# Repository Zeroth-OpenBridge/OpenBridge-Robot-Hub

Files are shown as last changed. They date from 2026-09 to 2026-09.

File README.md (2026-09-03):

# Robot Hub

Hardware boundary for **Zeroth Bridge** (小桥): drawings, electrical topology, enclosure / interface notes, and printable parts.

OpenBridge is the open-source ecosystem. Zeroth Bridge is the robot.

| Resource | Repository |
| --- | --- |
| Product introduction | [openbridge](https://github.com/Zeroth-OpenBridge/openbridge) |
| Skill development | [Skill Hub](https://github.com/Zeroth-OpenBridge/OpenBridge-Skill-Hub) |
| Simulation and verification | [Simulation Hub](https://github.com/Zeroth-OpenBridge/OpenBridge-Simulation-Hub) |

Document version: V1.1.1  
Hardware snapshot: **2026-09-02** (`mechanical/20260902/`)  
Applicable model: 小桥 / Zeroth Bridge  
Units: SI (cm, kg, N·m)  
License: [GNU General Public License v3.0](LICENSE) — 元点机器人 / OpenBridge

---

## Contents

1. [Repository layout](#repository-layout)
2. [Print quickstart](#print-quickstart)
3. [Parts snapshot 2026-09-02](#parts-snapshot-2026-09-02)
4. [Mechanical structure](#mechanical-structure)
5. [Specifications](#specifications)
6. [Degrees of freedom](#degrees-of-freedom)
7. [Electrical topology](#electrical-topology)
8. [Assembly](#assembly)
9. [Known limits](#known-limits)
10. [Issues and pull requests](#issues-and-pull-requests)
11. [License](#license)

---

## Repository layout

```
OpenBridge-Robot-Hub/
├── README.md
├── CHANGELOG.md
├── LICENSE
├── images/                      README figures (regular Git files, not LFS)
│   ├── 2.2-electrical-topology.png
│   ├── 4.1-structure.png        body structure diagram
│   └── 4.1-joints.png           joint index / motor layout
├── mechanical/
│   └── 20260902/                hardware snapshot 2026-09-02
│       ├── VERSION
│       ├── Zeroth_Bridge_assembly_20260902.step.zip
│       ├── head/
│       ├── torso/
│       ├── waist/
│       ├── left_arm/
│       ├── right_arm/
│       ├── left_leg/
│       ├── right_leg/
│       └── foot/
├── electrical/                  topology and wiring
│   └── electrical-topology.pdf  source diagram from the open-source prep doc
└── assembly/                    assembly and fastener notes
```

| Path | Status | What belongs here |
| --- | --- | --- |
| `mechanical/20260902/` | Published | Printable STL by body region, structural members, and zipped STEP assembly (snapshot 2026-09-02) |
| `electrical/` | Topology PDF published | Electrical topology and later wiring / pinout notes |
| `assembly/` | Placeholder | Assembly sequence and fasteners |
| `images/` | Published | Figures used by this README |

Later hardware drops use a new dated folder (`mechanical/YYYYMMDD/`) so snapshots stay side by side.

---

## Print quickstart

Current parts: [`mechanical/20260902/`](mechanical/20260902/). Left / right parts use `_L` / `_R`. Files named `structure_*` are structural members (series **1** foot, **2** shank, **3** thigh, **4–5** waist, **6** arm).

Print **TPU** for:

- Chest enclosure — `torso/body_front_shell.stl`, `torso/body_rear_shell.stl` (soft chest shell)
- `head/neck_tpu.stl`
- `torso/logo_tpu.stl`
- `foot/foot_sole_tpu.stl`

Slicer profiles and remaining material assignments are not in this revision.

Coming soon. Expected update in September.

---

## Parts snapshot 2026-09-02

Full-body STEP (zipped, about 28 MB): [`Zeroth_Bridge_assembly_20260902.step.zip`](mechanical/20260902/Zeroth_Bridge_assembly_20260902.step.zip). Uncompressed STEP (134 MB): [Releases](https://github.com/Zeroth-OpenBridge/OpenBridge-Robot-Hub/releases/tag/hardware-2026.09.02).

| Region | Path | Files |
| --- | ---: | --- |
| Head | [`head/`](mechanical/20260902/head/) | 9 STL |
| Torso | [`torso/`](mechanical/20260902/torso/) | 18 STL |
| Waist | [`waist/`](mechanical/20260902/waist/) | 11 STL |
| Left arm | [`left_arm/`](mechanical/20260902/left_arm/) | 17 STL |
| Right arm | [`right_arm/`](mechanical/20260902/right_arm/) | 18 STL |
| Left leg | [`left_leg/`](mechanical/20260902/left_leg/) | 24 STL + 1 PRT |
| Right leg | [`right_leg/`](mechanical/20260902/right_leg/) | 21 STL |
| Foot | [`foot/`](mechanical/20260902/foot/) | 9 STL |
| Assembly | [`Zeroth_Bridge_assembly_20260902.step.zip`](mechanical/20260902/Zeroth_Bridge_assembly_20260902.step.zip) | 1 ZIP |

Filenames match the part names (English). `_L` / `_R` is side. Browse each folder for the full list.

---

## Mechanical structure

Zeroth Bridge is a compact humanoid with a slender body. Key dimensions and mass follow the [specification table](#specifications) (85 cm / about 10 kg). The chest shell is soft TPU.

**Body structure diagram**

<p align="center">
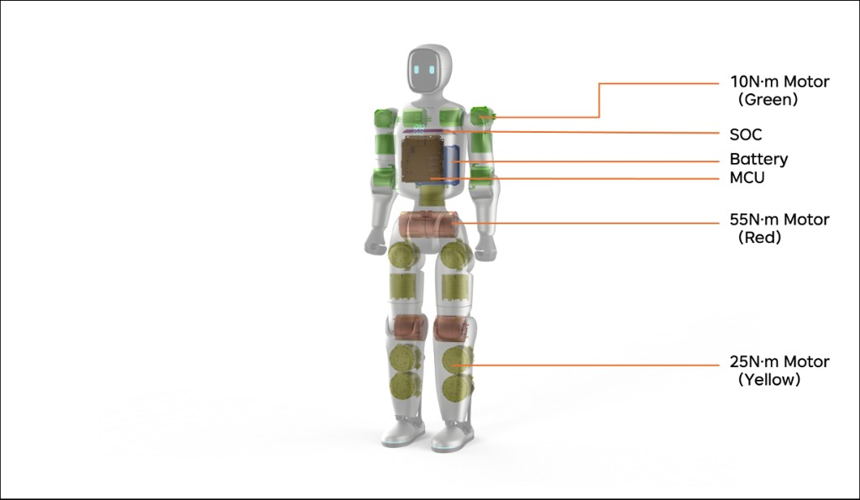
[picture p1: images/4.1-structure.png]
Zeroth Bridge body structure
  
</p>

Callouts on the cutaway:

- **10 N·m motor** (green) — shoulders and arms
- **SOC** — upper chest, below the neck
- **Battery** — blue pack in the torso
- **MCU** — chest controller board
- **55 N·m motor** (red) — hips and knees
- **25 N·m motor** (yellow) — thighs and ankles

**Joint range of motion and motor parameters**

<p align="center">
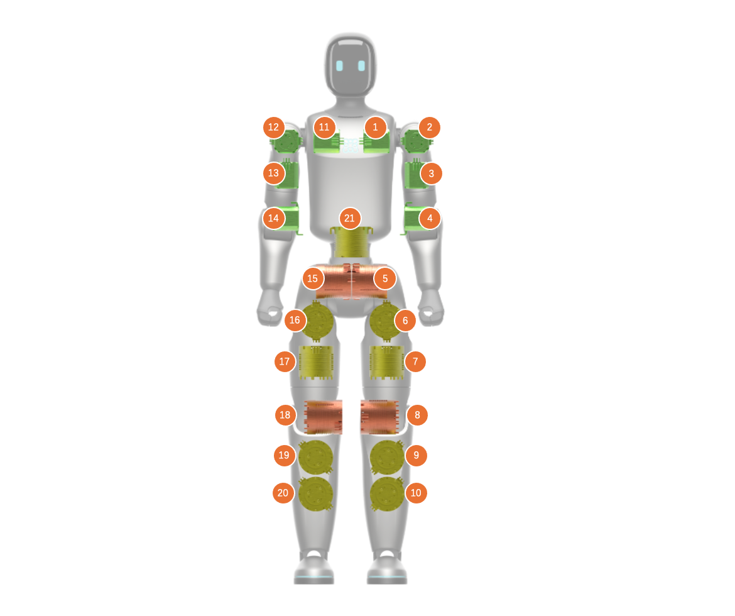
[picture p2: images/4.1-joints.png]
Joint range of motion and motor parameters
  
</p>

Orange tags **1–21** index joints: **1–4 right arm, 5–10 right leg, 11–14 left arm, 15–20 left leg, 21 waist.** Peak torques for each region are in the [DoF table](#degrees-of-freedom).

| # | Joint | Lower (deg) | Lower (rad) | Upper (deg) | Upper (rad) | Torque (N·m) | Speed (rpm) | Speed (rad/s) |
| --- | --- | ---: | ---: | ---: | ---: | ---: | ---: | ---: |
| 1 | right_shoulder_pitch | -210 | -3.6652 | 90 | 1.5708 | 10 | 235 | 24.6091 |
| 2 | right_shoulder_roll | -180 | -3.1416 | 10 | 0.1745 | 10 | 235 | 24.6091 |
| 3 | right_shoulder_yaw | -90 | -1.5708 | 90 | 1.5708 | 10 | 235 | 24.6091 |
| 4 | right_elbow_pitch | -45 | -0.7854 | 225 | 3.927 | 10 | 235 | 24.6091 |
| 5 | right_hip_pitch | -160 | -2.7925 | 160 | 2.7925 | 55 | 180 | 18.8496 |
| 6 | right_hip_roll | -80 | -1.3963 | 90 | 1.5708 | 25 | 170 | 17.8024 |
| 7 | right_hip_yaw | -160 | -2.7925 | 160 | 2.7925 | 25 | 170 | 17.8024 |
| 8 | right_knee_pitch | -100 | -1.7453 | 120 | 2.0944 | 55 | 180 | 18.8496 |
| 9 | right_ankle_pitch | -40 | -0.6981 | 40 | 0.6981 | 25 | 170 | 17.8024 |
| 10 | right_ankle_roll | -28 | -0.4887 | 28 | 0.4887 | 25 | 170 | 17.8024 |
| 11 | left_shoulder_pitch | -210 | -3.6652 | 90 | 1.5708 | 10 | 235 | 24.6091 |
| 12 | left_shoulder_roll | -10 | -0.1745 | 180 | 3.1416 | 10 | 235 | 24.6091 |
| 13 | left_shoulder_yaw | -90 | -1.5708 | 90 | 1.5708 | 10 | 235 | 24.6091 |
| 14 | left_elbow_pitch | -45 | -0.7854 | 225 | 3.927 | 10 | 235 | 24.6091 |
| 15 | left_hip_pitch | -160 | -2.7925 | 160 | 2.7925 | 55 | 180 | 18.8496 |
| 16 | left_hip_roll | -90 | -1.5708 | 80 | 1.3963 | 25 | 170 | 17.8024 |
| 17 | left_hip_yaw | -160 | -2.7925 | 160 | 2.7925 | 25 | 170 | 17.8024 |
| 18 | left_knee_pitch | -100 | -1.7453 | 120 | 2.0944 | 55 | 180 | 18.8496 |
| 19 | left_ankle_pitch | -40 | -0.6981 | 40 | 0.6981 | 25 | 170 | 17.8024 |
| 20 | left_ankle_roll | -28 | -0.4887 | 28 | 0.4887 | 25 | 170 | 17.8024 |
| 21 | waist_yaw | -155 | -2.7053 | 155 | 2.7053 | 25 | 170 | 17.8024 |

---

## Specifications

| Key spec | Value | Notes |
| --- | --- | --- |
| Overall height | 85 cm | ~80 cm-class small humanoid; suited to demonstrations, education, teleoperation, and small-object interaction |
| Shoulder height | 73 cm | Suited to low tabletops, children's desks, and near-floor motion demos; not suited to fine manipulation at adult kitchen counters |
| Hip / base height | 50 cm | Sets gait center of mass, fall height, and safety-test bounds |
| Leg length | ~50 cm | Structural segment length affects routing, enclosure, and mechanical stacking; Z-axis projected length affects standing height and gait |
| Arm length | 30–40 cm, two-finger gripper | Short-arm motion demo / teleoperation platform |
| Shoulder width | 13 cm between joint centers | Controlled without sacrificing self-collision clearance |
| Overall mass | ~10 kg | Lightweight, highly dynamic |

---

## Degrees of freedom

| Body region | Joint | DoF | Peak torque |
| --- | --- | --- | --- |
| Arms | Shoulder up/down | 1 | 10 N·m |
|  | Shoulder front/back | 1 | 10 N·m |
|  | Shoulder in/out | 1 | 10 N·m |
|  | Elbow up/down | 1 | 10 N·m |
| Waist | Waist rotation | 1 | 25 N·m |
| Legs | Hip | 1 | 55 N·m |
|  | Thigh | 2 | 25 N·m |
|  | Knee | 1 | 55 N·m |
|  | Ankle | 2 | 25 N·m |

---

## Electrical topology

Original file: [`electrical/electrical-topology.pdf`](electrical/electrical-topology.pdf). 

<p align="center">
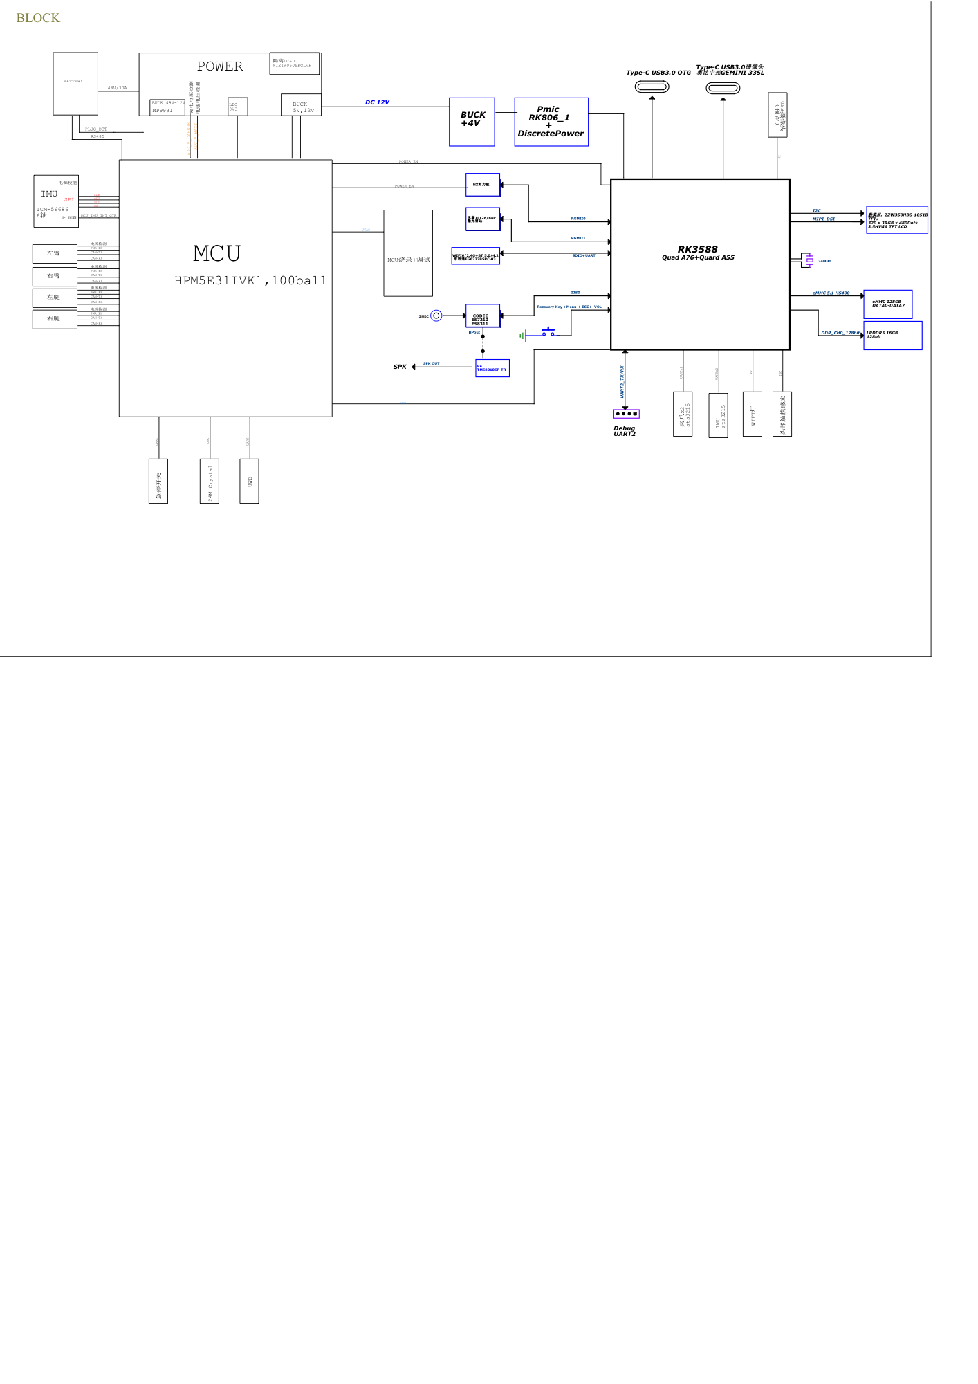
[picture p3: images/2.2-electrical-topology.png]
Zeroth Bridge electrical topology
  
</p>

Two compute domains share the body:

- **MCU** (HPM5E31IVK1) — real-time motion. Dedicated buses to left arm, right arm, left leg, and right leg; IMU on SPI/I2C; crystal, USB, and a programming/debug path toward the SoC.
- **SoC** (RK3588, quad-core A76 + quad-core A55) — application compute. LPDDR5 16 GB, eMMC 128 GB (HS400), LCD (320×384 @ 60 Hz), audio codec ES7210 / ES8311 to speaker, Wi-Fi/BT, USB 3.0 Type-C OTG, Type-C for GEMINI 335L, debug UART2, fan control, and a 9-axis gyro link.

MCU and SoC exchange data over dual **RGMII** links. Battery power goes through a **12 V buck**; the MCU rail set is 12 V / 5 V / 3.3 V; the SoC path is 12 V → buck +4 V → PMIC RK806 plus discrete regulators.

---

## Assembly

Coming soon. Expected update in September.

---

## Known limits

- Current sensing is IMU plus motor-internal feedback. LiDAR and cameras are not fitted; hardware interfaces are reserved.
- Collision energy is lower than a hard enclosure, but this is still a high-dynamic ~10 kg machine.
- Arm reach is short (30–40 cm). Not intended for fine work at adult kitchen-counter height.
- Fasteners and assembly steps are not published in this revision. Printable STL and the STEP assembly are in `mechanical/20260902/`.

If you build or modify a complete robot yourself, assess close-to-people use and high-dynamic motion risk on your own.

---

## Issues and pull requests

Use [GitHub Issues](https://github.com/Zeroth-OpenBridge/OpenBridge-Robot-Hub/issues) for defects, missing files, and doc gaps. Pull requests should stay scoped (one drawing set, one electrical note, or one README fix). Do not commit secrets or files over 100 MB; attach those to Releases.

Each public release is recorded in [CHANGELOG.md](CHANGELOG.md) and tagged.

---

## License

[GNU General Public License v3.0](LICENSE). Copyright 2026 元点机器人 / OpenBridge.

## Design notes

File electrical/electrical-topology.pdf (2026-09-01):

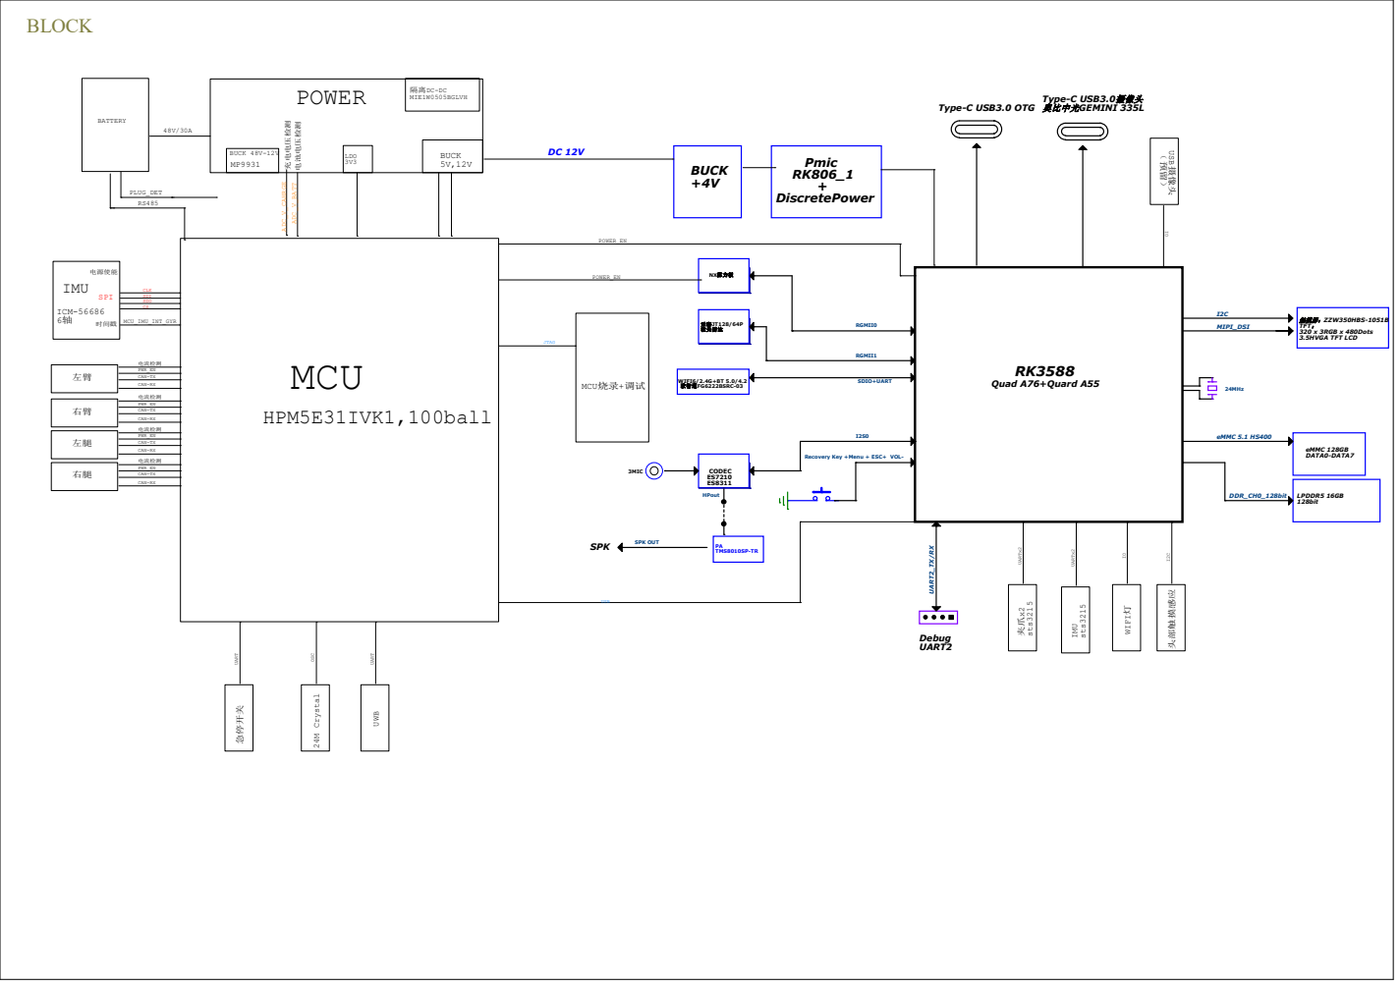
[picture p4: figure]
BLOCK; MCU; HPM5E31IVK1,100ball; IMU; ICM-56686 6轴; CLK; MCU_IMU_INT_GYR 左臂; SDI SDO CS; CAN-TX; BUCK 48V-12V ADC_V_CAHRGE; ADC_V_BATT 充电电压检测 电池电压检测; POWER; BUCK 5V,12V; LDO 3V3; POWER_EN; JTAG; MCU烧录+调试; 电源使能; SPI 时间戳; BATTERY; PLUG_DET; CAN-RX; PWR_EN 右臂; PWR_EN; CAN-RX 左腿; CAN-RX 右腿; 电流检测; WIFI6/2.4G+BT 5.0/4.2 欧智通FG6222BSRC-03; 禾赛JT128/64P 激光雷达; NX算力板; SDIO+UART; DDR_CH0_128bit; RGMII0; RGMII1; Type-C USB3.0摄像头 奥比中光GEMINI 335L; SPK; Recovery Key +Menu + ESC+ VOL-; Debug UART2; eMMC 128GB DATA0-DATA7; 24MHz; eMMC 5.1 HS400; Quad A76+Quard A55; PA TMS8010SP-TR; HPout; CODEC ES7210 ES8311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

I2C UARTx2 夹爪x2 sts3215 | UARTx2 IMU sts3215 急停开关 UART | WIFI灯 IO | IO USB摄像头 （预留） I2C 头部触摸感应 24M Crystal OSC

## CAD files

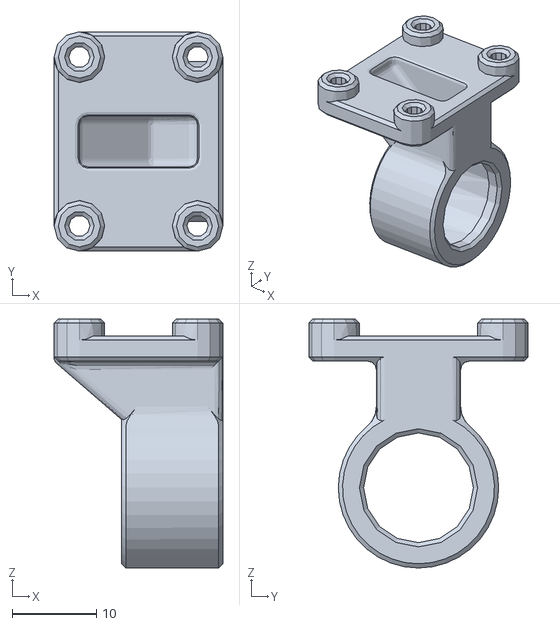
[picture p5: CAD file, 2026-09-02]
mechanical/20260902/foot/structure_1_1-01.stl
20.0 x 26.0 x 29.5

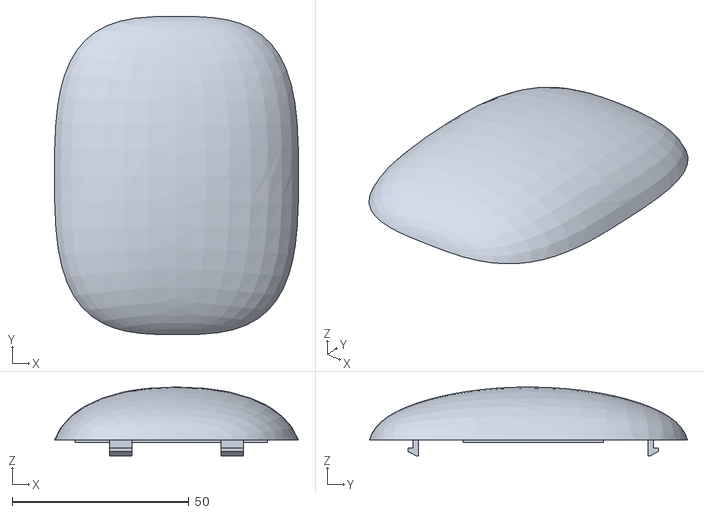
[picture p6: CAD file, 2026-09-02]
mechanical/20260902/head/face_shell.stl
69.0 x 90.0 x 19.5

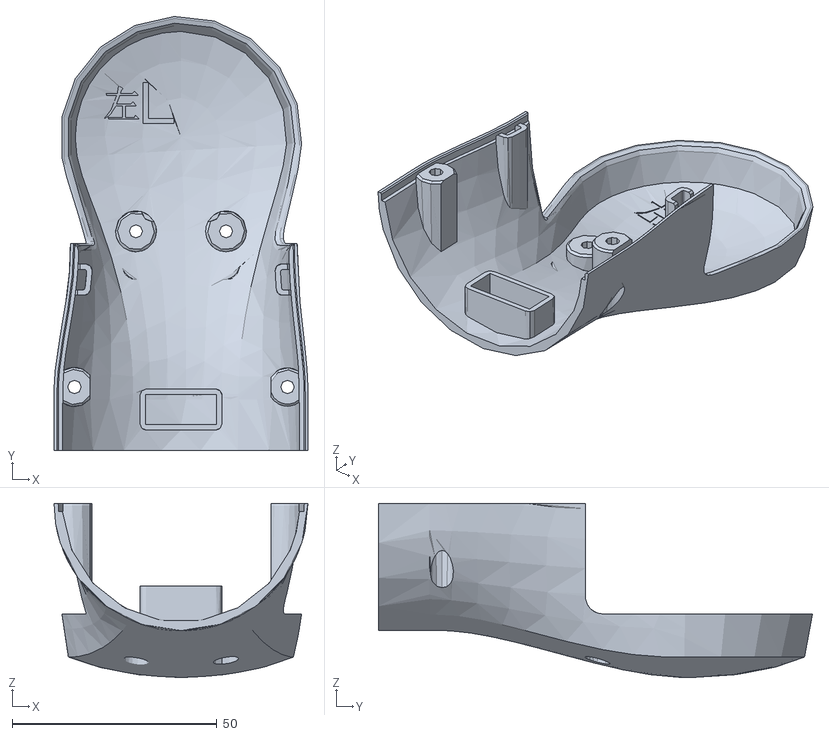
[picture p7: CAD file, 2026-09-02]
mechanical/20260902/left_arm/upper_arm_back_cover_L.stl
62.0 x 105.9 x 42.5

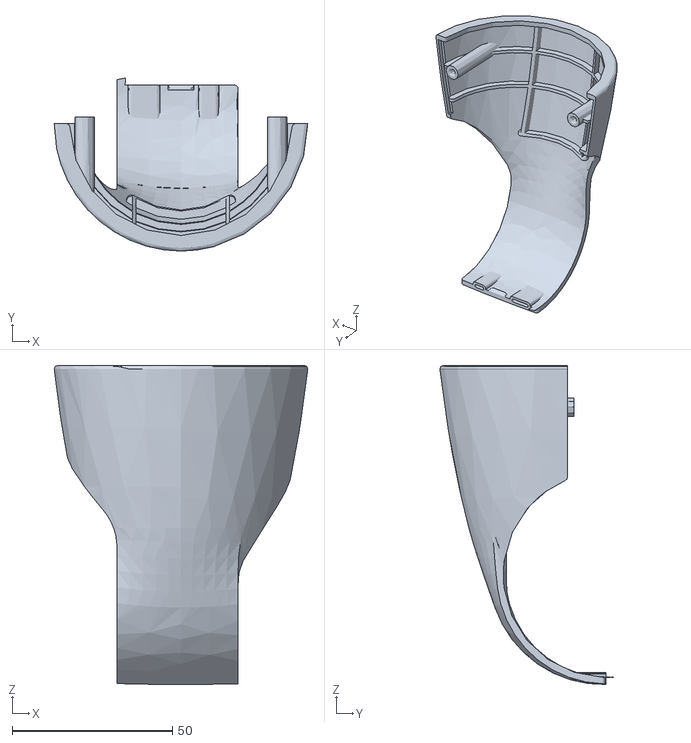
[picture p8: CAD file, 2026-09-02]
mechanical/20260902/left_leg/knee_front_shell_L.stl
79.1 x 54.0 x 99.5

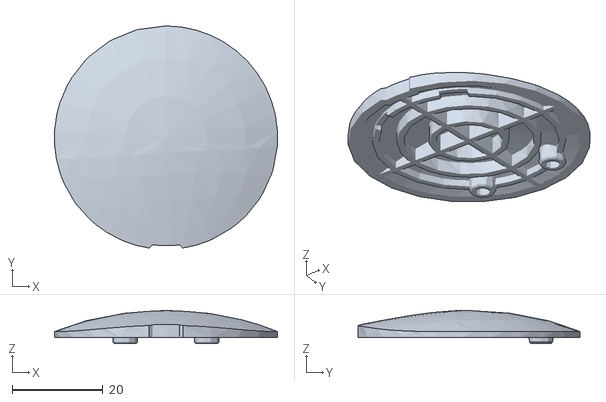
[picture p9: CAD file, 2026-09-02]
mechanical/20260902/right_arm/shoulder_servo_cover.stl
49.1 x 48.9 x 7.30

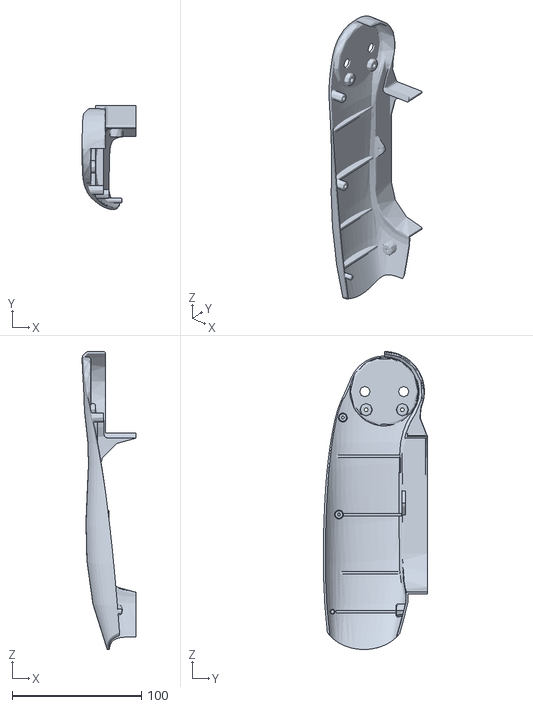
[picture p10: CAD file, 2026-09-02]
mechanical/20260902/right_leg/shank_outer_shell_R.stl
41.5 x 80.6 x 230.2

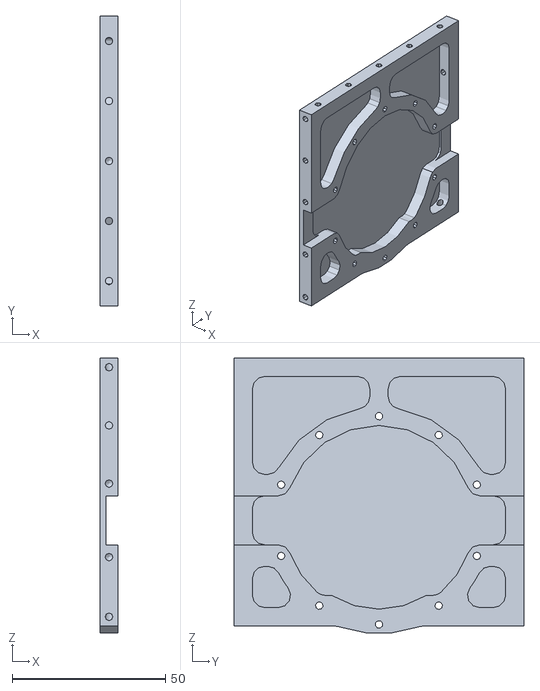
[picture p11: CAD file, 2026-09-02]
mechanical/20260902/torso/frame_battery_bottom.stl
6.00 x 94.7 x 89.8

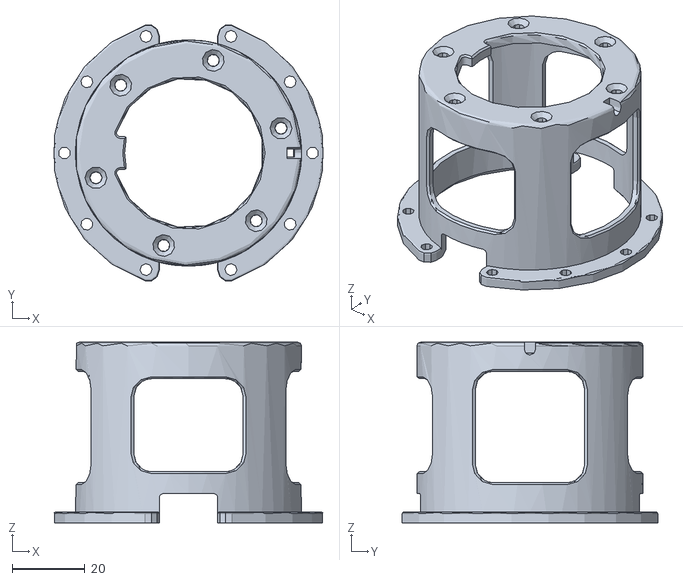
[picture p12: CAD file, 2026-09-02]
mechanical/20260902/waist/structure_5-1.stl
73.7 x 70.1 x 49.5

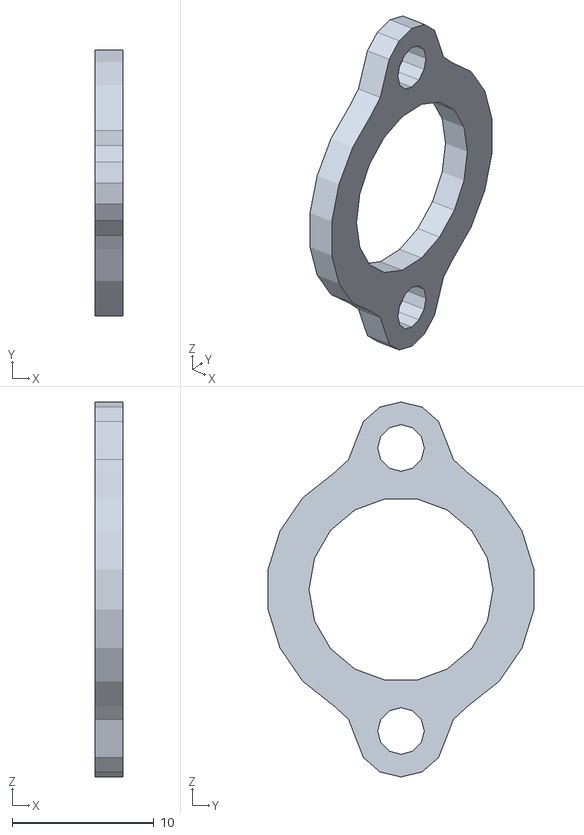
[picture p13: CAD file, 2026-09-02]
mechanical/20260902/foot/structure_1-3.stl
2.00 x 18.8 x 26.5

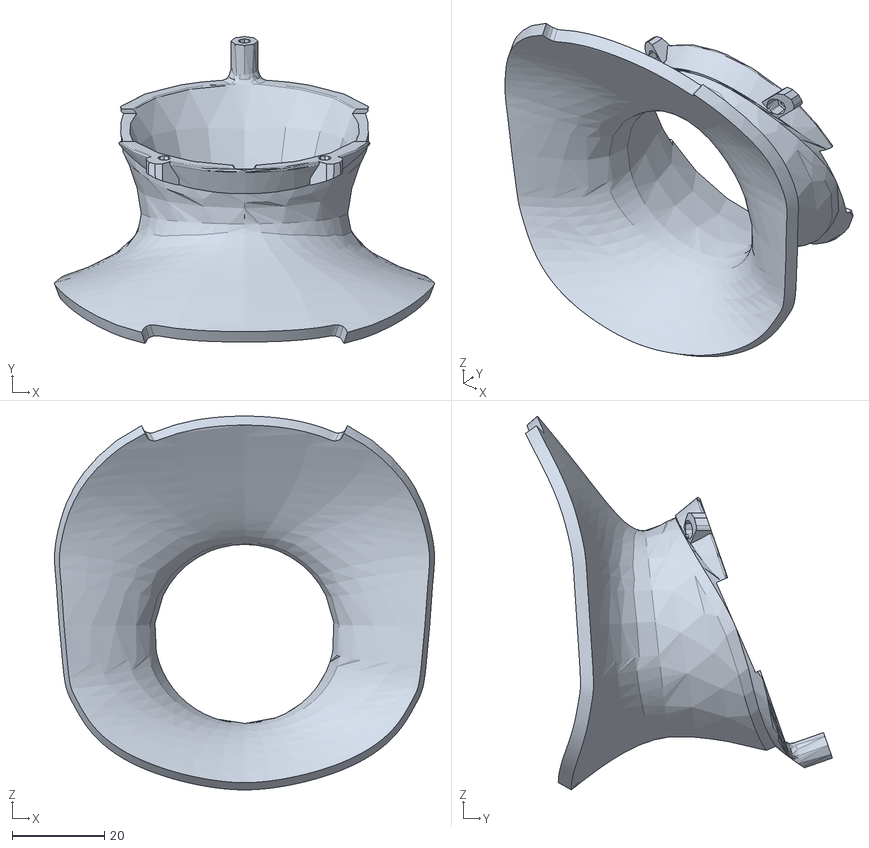
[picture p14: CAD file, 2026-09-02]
mechanical/20260902/head/neck_tpu.stl
82.3 x 66.5 x 81.0

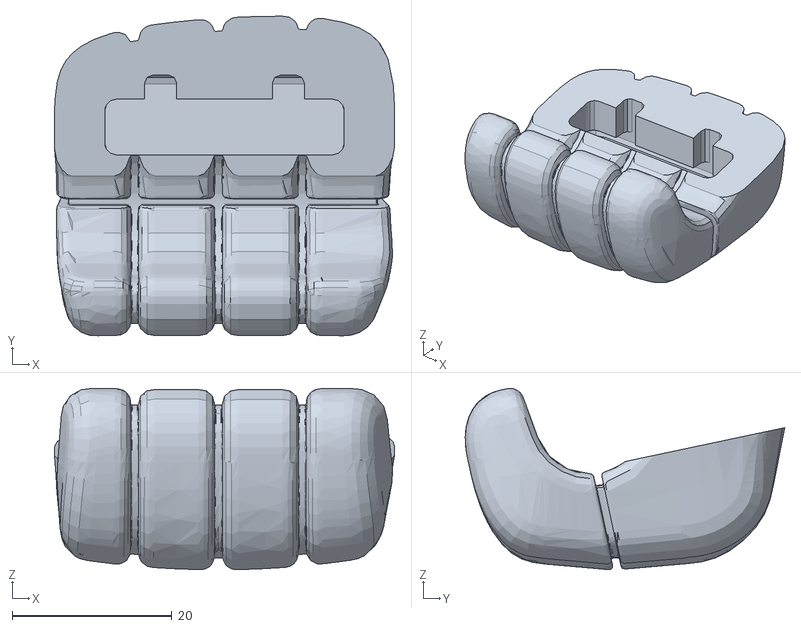
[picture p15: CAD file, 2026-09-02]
mechanical/20260902/left_arm/handfinger_L.stl
42.6 x 40.0 x 22.7

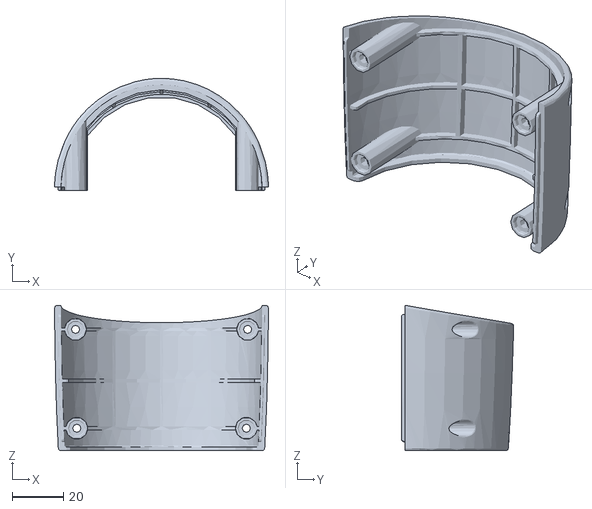
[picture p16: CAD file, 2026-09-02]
mechanical/20260902/left_leg/hip_thigh_rear_shell_L.stl
83.3 x 43.7 x 56.6

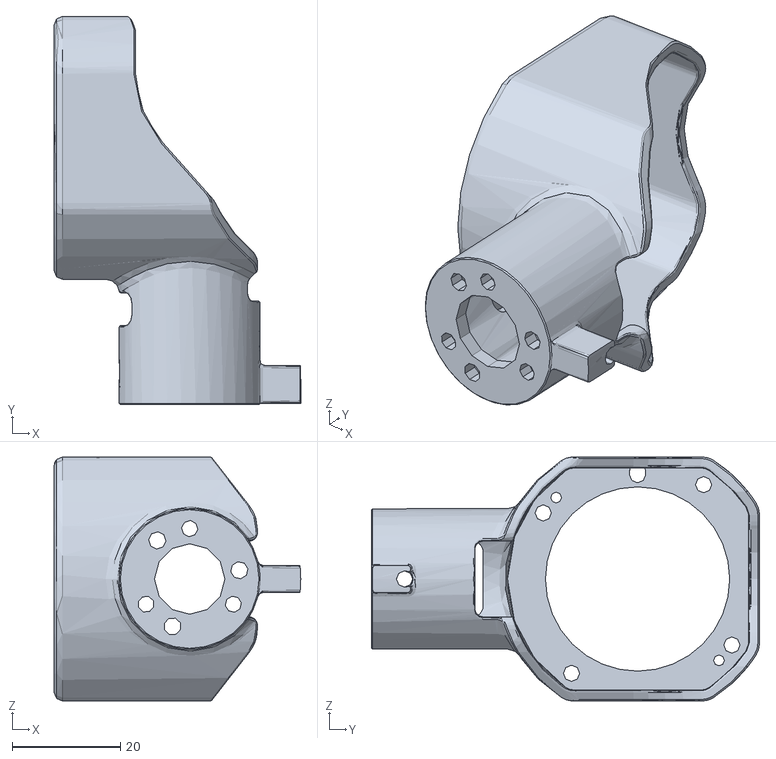
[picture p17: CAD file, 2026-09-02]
mechanical/20260902/right_arm/structure_6L_3-1_R.stl
45.5 x 71.6 x 45.0

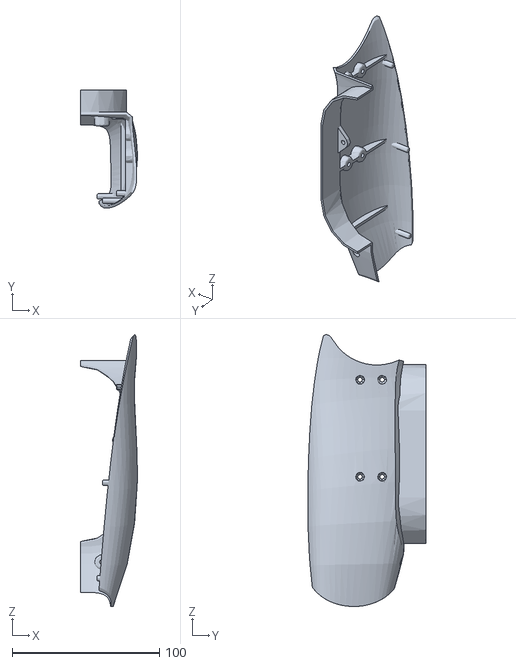
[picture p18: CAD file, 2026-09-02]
mechanical/20260902/right_leg/shank_inner_shell_R.stl
38.6 x 80.6 x 185.0

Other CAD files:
mechanical/20260902/torso/frame_front_side_rib_1.stl
mechanical/20260902/waist/imu_support.stl
mechanical/20260902/foot/foot_upper.stl
mechanical/20260902/head/face_panel.stl
mechanical/20260902/foot/foot_sole.stl
mechanical/20260902/foot/foot_sole_tpu.stl
mechanical/20260902/foot/structure_1-4.stl
mechanical/20260902/foot/structure_1_1-02.stl
mechanical/20260902/foot/structure_1_1-1.stl
mechanical/20260902/foot/structure_1_1-2.stl
mechanical/20260902/head/head_shell_lower.stl
mechanical/20260902/head/head_shell_upper.stl
mechanical/20260902/head/heatsink.stl
mechanical/20260902/head/neck_frame.stl
mechanical/20260902/head/neck_light_bar.stl
mechanical/20260902/head/screen_silicone_strip.stl
mechanical/20260902/left_arm/elbow_cover_L.stl
mechanical/20260902/left_arm/forearm_inside_L.stl
mechanical/20260902/left_arm/forearm_outside_L.stl
mechanical/20260902/left_arm/handpalm_L.stl
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

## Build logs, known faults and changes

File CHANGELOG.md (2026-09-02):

# Changelog

## [V1.1.1]

- Author: OpenBridge Official
- Changes: Add zipped STEP assembly to mechanical/20260902

## [V1.1.0]

- Author: OpenBridge Official
- Changes: Publish hardware snapshot 2026-09-02 (printable STL by body region); STEP assembly on GitHub Releases; remove unused BOM folder

## [V1.0.2]

- Author: OpenBridge Official
- Changes: Replace the body structure diagram with the English-labeled figure

## [V1.0.1]

- Author: OpenBridge Official
- Changes: Add repository catalog, electrical topology (2.2), and mechanical structure (4.1)

## [V1.0.0]

- Author: OpenBridge Official
- Changes: Initial documentation

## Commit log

2026-09-01 Add joint range and motor parameter table from Feishu, and drop placeholder notes that no longer apply.
2026-09-02 Publish the 2026-09-02 hardware snapshot and remove the unused BOM folder.
    Printable STL files are under mechanical/20260902. The STEP assembly exceeds GitHub’s file limit and will be attached to a Release.
    [battery_button.stl, battery_cover.stl, body_front_shell.stl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]
2026-09-02 Add the zipped STEP assembly to the 2026-09-02 hardware snapshot.
2026-10-13 Replace the 2026-09-02 STL snapshot with native CAD from 2026-10-12.
    Publish Creo/ProE .prt/.asm under mechanical/20261012. The full-body STEP exceeds GitHub’s file limit and will be attached to a Release.
2026-10-13 Add the STEP assembly download link in the Assembly section.
